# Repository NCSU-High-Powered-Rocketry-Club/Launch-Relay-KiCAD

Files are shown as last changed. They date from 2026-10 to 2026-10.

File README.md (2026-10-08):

# Launch Relay KiCad
This project contains the KiCad files for HPRC's Launch Relay board. This PCB was designed for the club's rover payload, which will be flown in the 2027 IREC competition.

## Description
The Launch Relay is designed to help conserve battery life and processing power of the rover payload by acting as a very low-power isolated solid-state relay. The board features an STM32 microcontroller, onboard flash for logging data, and an accelerometer to detect when the rocket launches and lands. It is all powered from a standard coin cell battery.

The firmware for the STM32 can be found [here](https://github.com/NCSU-High-Powered-Rocketry-Club/GildedTrigger).



## Component Overview
Here are the main components that the board uses:

| Component Type | Part Number | Datasheet |
|---|---|---|
| Microcontroller | STM32U083KCU6 | [STMicroelectronics](https://www.st.com/resource/en/datasheet/stm32u083kc.pdf) |
| Accelerometer | BMA580 | [Bosch Sensortec](https://www.bosch-sensortec.com/media/boschsensortec/downloads/datasheets/bst-bma580-ds000.pdf) |
| SPI NOR Flash (32 Mbit) | MX25R3235FM1IL0 | [Macronix](https://www.macronix.com/Lists/Datasheet/Attachments/8755/MX25R3235F%2C%20Wide%20Range%2C%2032Mb%2C%20v1.8.pdf) |
| D-Type Flip-Flop | SN74LVC1G74DQER | [Texas Instruments](https://www.ti.com/lit/ds/symlink/sn74lvc1g74.pdf) |
| N-Channel Power MOSFET | NVMFS5C460NLAFT1G-YE | [onsemi](https://www.onsemi.com/pdf/datasheet/nvmfs5c460nl-d.pdf) |

The STM32 was chosen for it's lower power consumption and small footprint, while still offering the needed peripherals for the board. The BMA580 accelerometer has excellent programmable interrupt features, allowing for customizable acceleration slopes and durations to be used to detect launch and wake the STM32. After launch, the acceleration data is stored to the MX25R3235F flash, which can be later retrieved for post-processing using the UART and DUMP pin provided on the pin header.

The board has two independent solid-state relays and are controlled using optocouplers. Optocouplers have relatively high power consumption compared to the rest of the board so a flip-flop circuit is used to limit the duration the optocoupler is powered. This powers the gate of the power MOSFET, which is wired as a low-side switch for the external circuit. Both relays on the board are designed for loads up to 10A. External circits must be at least 5.1V.

## Libraries
Some of the KiCad symbols and footprints for this project are not included in the standard KiCad library, and are located in [HPRC's KiCad Library](https://github.com/NCSU-High-Powered-Rocketry-Club/HPRC-KiCad-Library)

## PCBWay
A special thank you to our sponsor, [PCBWay](https://www.pcbway.com/), for supporting the manufacturing of this custom PCB! As a competitive high-powered rocketry team, reliable electronics are essential to the success of our projects. PCBWay's high-quality PCB manufacturing services have helped us turn our designs into functional hardware, allowing us to develop and test custom electronics for our rockets and payloads. Their support, attention to detail, and excellent communication throughout the manufacturing process have been greatly appreciated. We are grateful for their contribution to our team's success and highly recommend checking out their services for your next electronics project!



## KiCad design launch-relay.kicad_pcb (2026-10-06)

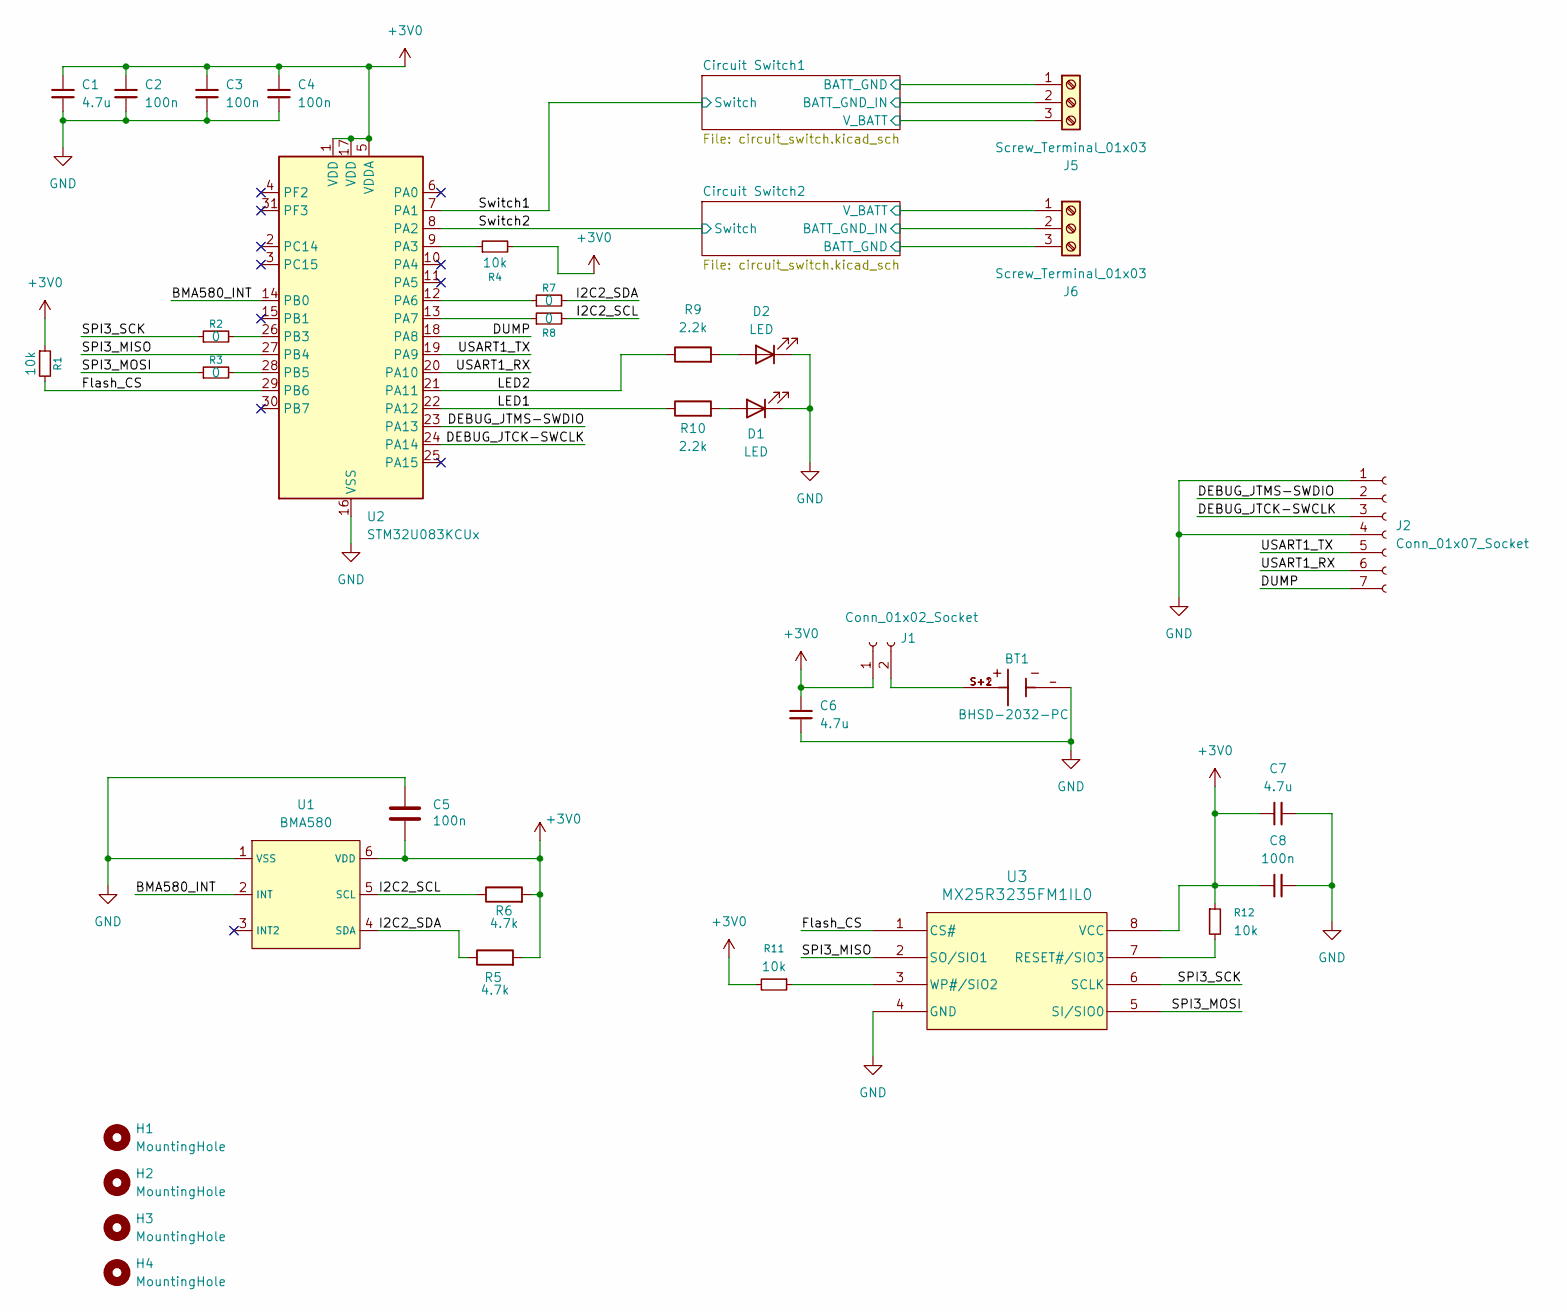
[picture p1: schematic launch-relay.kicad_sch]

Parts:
BT1: BHSD-2032-PC; BAT_BHSD-2032-PC; PARTREV K
C1, C6, C7: 4.7u; C_0402_1005Metric; Manufacturer_Part_Number GRM155R60J475ME47D
C2, C3, C4, C5, C8: 100n; C_0402_1005Metric; Manufacturer_Part_Number GRM155R61A104KA01D
D1: LED; LED_0805_2012Metric; Manufacturer_Part_Number APT2012SURCK
D2: LED; LED_0805_2012Metric; Manufacturer_Part_Number APT2012CGCK
H1, H2, H3, H4: MountingHole; MountingHole_2.2mm_M2
J1: Conn_01x02_Socket; PinSocket_1x02_P2.54mm_Vertical
J2: Conn_01x07_Socket; PinSocket_1x07_P2.54mm_Vertical
J5, J6: Screw_Terminal_01x03; TerminalBlock_Philmore_TB133_1x03_P5.00mm_Horizontal
R1, R4, R11, R12: 10k; R_0402_1005Metric; Manufacturer_Part_Number RC0402FR-0710KL
R2, R3, R7, R8: 0; R_0402_1005Metric; Manufacturer_Part_Number RC0402FR-070RL
R5, R6: 4.7k; R_0402_1005Metric; Manufacturer_Part_Number RC0402FR-074k7L
R9, R10: 2.2k; R_0402_1005Metric; Manufacturer_Part_Number RC0402FR-072k2L
U1: BMA580; Manufacturer_Part_Number BMA580
U2: STM32U083KCUx; QFN-32-1EP_5x5mm_P0.5mm_EP3.45x3.45mm; Manufacturer_Part_Number STM32U083KCU6
U3: MX25R3235FM1IL0; SOP_8L_150_MAC; Manufacturer_Part_Number MX25R3235FM1IL0

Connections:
+3V0: C1.2, C2.2, C3.2, C4.2, C5.2, C6.2, C7.1, C8.1, J1.1, R1.1, R4.2, R5.2, R6.2, R11.2, R12.1, U1.6 (VDD), U2.1 (VDD), U2.5 (VDDA), U2.17 (VDD), U3.8 (VCC)
/BMA580_INT: U1.2 (INT), U2.14 (PB0)
/Circuit Switch1/BATT_GND: J5.1; also elsewhere on the board
/Circuit Switch1/BATT_GND_IN: J5.2; also elsewhere on the board
/Circuit Switch1/V_BATT: J5.3; also elsewhere on the board
/Circuit Switch2/BATT_GND: J6.3; also elsewhere on the board
/Circuit Switch2/BATT_GND_IN: J6.2; also elsewhere on the board
/Circuit Switch2/V_BATT: J6.1; also elsewhere on the board
/DEBUG_JTCK-SWCLK: J2.3, U2.24 (PA14)
/DEBUG_JTMS-SWDIO: J2.2, U2.23 (PA13)
/DUMP: J2.7, U2.18 (PA8)
/Flash_CS: R1.2, U2.29 (PB6), U3.1 (CS#)
/I2C2_SCL: R6.1, R8.2, U1.5 (SCL)
/I2C2_SDA: R5.1, R7.2, U1.4 (SDA)
/LED1: R10.1, U2.22 (PA12)
/LED2: R9.1, U2.21 (PA11)
/SPI3_MISO: U2.27 (PB4), U3.2 (SO/SIO1)
/SPI3_MOSI: R3.1, U3.5 (SI/SIO0)
/SPI3_SCK: R2.1, U3.6 (SCLK)
/Switch1: U2.7 (PA1); also elsewhere on the board
/Switch2: U2.8 (PA2); also elsewhere on the board
/USART1_RX: J2.6, U2.20 (PA10)
/USART1_TX: J2.5, U2.19 (PA9)
GND: BT1.-, C1.1, C2.1, C3.1, C4.1, C5.1, C6.1, C7.2, C8.2, D1.1 (K), D2.1 (K), J2.1, J2.4, U1.1 (VSS), U2.16 (VSS), U2.32 (VSS), U2.33 (VSS), U3.4 (GND); also elsewhere on the board
unnamed: D1.2 (A), R10.2
unnamed: D2.2 (A), R9.2
unnamed: BT1.S+1, BT1.S+2, J1.2
unnamed: R4.1, U2.9 (PA3)
unnamed: R7.1, U2.12 (PA6)
unnamed: R8.1, U2.13 (PA7)
unnamed: R2.2, U2.26 (PB3)
unnamed: R3.2, U2.28 (PB5)
unnamed: R12.2, U3.7 (RESET#/SIO3)
unnamed: R11.1, U3.3 (WP#/SIO2)

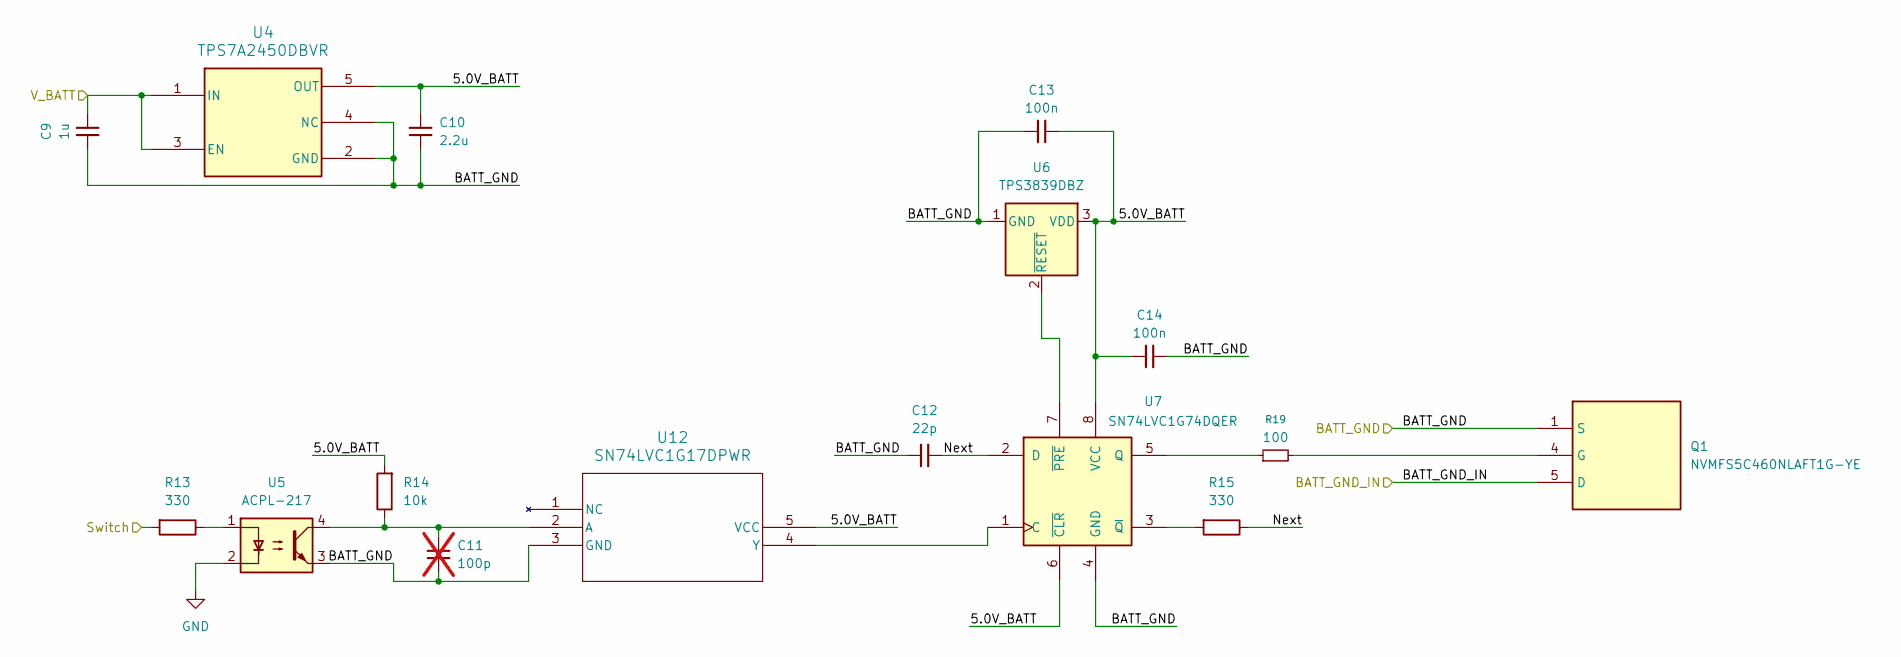
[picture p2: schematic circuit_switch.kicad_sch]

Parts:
C9: 1u; C_0402_1005Metric; Manufacturer_Part_Number GRM155R61E105MA12D
C10: 2.2u; C_0402_1005Metric; Manufacturer_Part_Number GRT155R61A225KE01D
C11: 100p; C_0402_1005Metric; not fitted
C12: 22p; C_0402_1005Metric; Manufacturer_Part_Number GRM1555C1H220JA01D
C13, C14: 100n; C_0402_1005Metric; Manufacturer_Part_Number GRM155R61A104KA01D
Q1: NVMFS5C460NLAFT1G-YE; NVMFS3D0P04M8LT1G; Manufacturer_Part_Number NVMFS5C460NLAFT1G-YE
R13, R15: 330; R_0402_1005Metric; Manufacturer_Part_Number RC0402FR-07330RL
R14: 10k; R_0402_1005Metric; Manufacturer_Part_Number RC0402FR-0710KL
R19: 100; R_0402_1005Metric; Manufacturer_Part_Number RC0402FR-07100RL
U4: TPS7A2450DBVR; SOT-23-5; Manufacturer_Part_Number TPS7A2450DBVR
U5: ACPL-217; SO-4_4.4x2.3mm_P1.27mm; Manufacturer_Part_Number ACPL-217-56CE
U6: TPS3839DBZ; SOT-23; Manufacturer_Part_Number TPS3839K50DBZR
U7: SN74LVC1G74DQER; X2SON-8_1.4x1mm_P0.35mm; Manufacturer_Part_Number SN74LVC1G74DQER
U12: SN74LVC1G17DPWR; Manufacturer_Part_Number SN74LVC1G17DPWR

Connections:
/Circuit Switch1/5.0V_BATT: C10.1, C13.1, C14.2, R14.2, U4.5 (OUT), U6.3 (VDD), U7.6 (~CLR), U7.8 (VCC), U12.5 (VCC)
/Circuit Switch1/BATT_GND: C9.1, C10.2, C11.1, C12.1, C13.2, C14.1, Q1.1 (S), Q1.2 (S), Q1.3 (S), U4.2 (GND), U4.4 (NC), U5.3, U6.1 (GND), U7.4 (GND), U12.3 (GND); also elsewhere on the board
/Circuit Switch1/BATT_GND_IN: Q1.5 (D), Q1.6 (D), Q1.7 (D), Q1.8 (D), Q1.9 (D); also elsewhere on the board
/Circuit Switch1/Next: C12.2, R15.1, U7.2 (D)
/Circuit Switch1/V_BATT: C9.2, U4.1 (IN), U4.3 (EN); also elsewhere on the board
/Switch1: R13.2; also elsewhere on the board
GND: U5.2; also elsewhere on the board
unnamed: Q1.4 (G), R19.2
unnamed: R13.1, U5.1
unnamed: U6.2 (~RESET), U7.7 (~PRE)
unnamed: R19.1, U7.5 (Q)
unnamed: R15.2, U7.3 (~Q)
unnamed: C11.2, R14.1, U5.4, U12.2 (A)
unnamed: U7.1 (C), U12.4 (Y)

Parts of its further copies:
C15: 1u; C_0402_1005Metric; Manufacturer_Part_Number GRM155R61E105MA12D
C16: 2.2u; C_0402_1005Metric; Manufacturer_Part_Number GRT155R61A225KE01D
C17: 100p; C_0402_1005Metric; not fitted
C18: 22p; C_0402_1005Metric; Manufacturer_Part_Number GRM1555C1H220JA01D
C19, C20: 100n; C_0402_1005Metric; Manufacturer_Part_Number GRM155R61A104KA01D
Q2: NVMFS5C460NLAFT1G-YE; NVMFS3D0P04M8LT1G; Manufacturer_Part_Number NVMFS5C460NLAFT1G-YE
R16, R18: 330; R_0402_1005Metric; Manufacturer_Part_Number RC0402FR-07330RL
R17: 10k; R_0402_1005Metric; Manufacturer_Part_Number RC0402FR-0710KL
R20: 100; R_0402_1005Metric; Manufacturer_Part_Number RC0402FR-07100RL
U8: TPS7A2450DBVR; SOT-23-5; Manufacturer_Part_Number TPS7A2450DBVR
U9: ACPL-217; SO-4_4.4x2.3mm_P1.27mm; Manufacturer_Part_Number ACPL-217-56CE
U10: TPS3839DBZ; SOT-23; Manufacturer_Part_Number TPS3839K50DBZR
U11: SN74LVC1G74DQER; X2SON-8_1.4x1mm_P0.35mm; Manufacturer_Part_Number SN74LVC1G74DQER
U13: SN74LVC1G17DPWR; Manufacturer_Part_Number SN74LVC1G17DPWR

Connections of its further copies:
/Circuit Switch2/5.0V_BATT: C16.1, C19.1, C20.2, R17.2, U8.5 (OUT), U10.3 (VDD), U11.6 (~CLR), U11.8 (VCC), U13.5 (VCC)
/Circuit Switch2/BATT_GND: C15.1, C16.2, C17.1, C18.1, C19.2, C20.1, Q2.1 (S), Q2.2 (S), Q2.3 (S), U8.2 (GND), U8.4 (NC), U9.3, U10.1 (GND), U11.4 (GND), U13.3 (GND); also elsewhere on the board
/Circuit Switch2/BATT_GND_IN: Q2.5 (D), Q2.6 (D), Q2.7 (D), Q2.8 (D), Q2.9 (D); also elsewhere on the board
/Circuit Switch2/Next: C18.2, R18.1, U11.2 (D)
/Circuit Switch2/V_BATT: C15.2, U8.1 (IN), U8.3 (EN); also elsewhere on the board
/Switch2: R16.2; also elsewhere on the board
GND: U9.2; also elsewhere on the board
unnamed: Q2.4 (G), R20.2
unnamed: R16.1, U9.1
unnamed: U10.2 (~RESET), U11.7 (~PRE)
unnamed: U11.1 (C), U13.4 (Y)
unnamed: R20.1, U11.5 (Q)
unnamed: R18.2, U11.3 (~Q)
unnamed: C17.2, R17.1, U9.4, U13.2 (A)

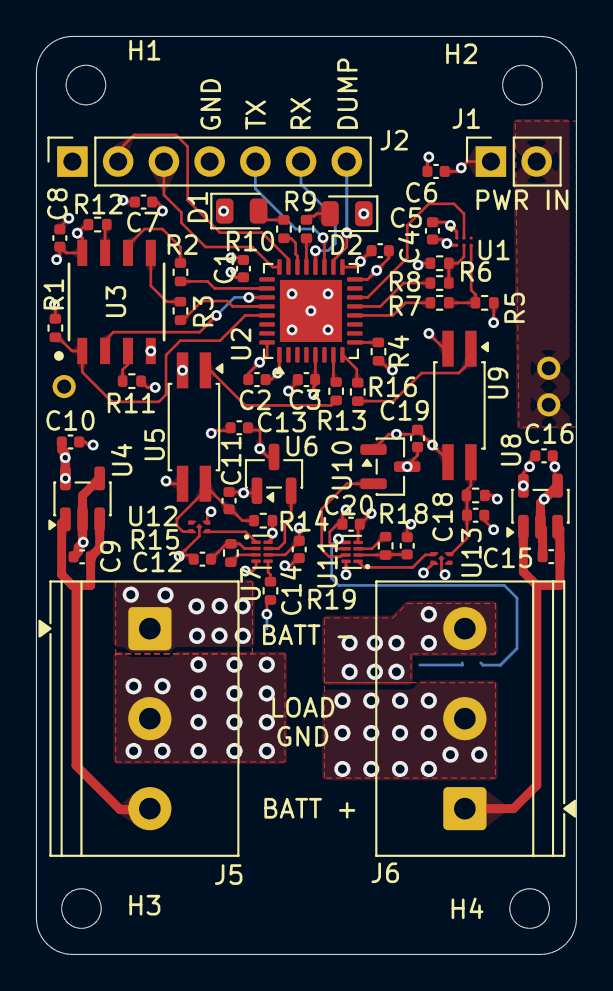
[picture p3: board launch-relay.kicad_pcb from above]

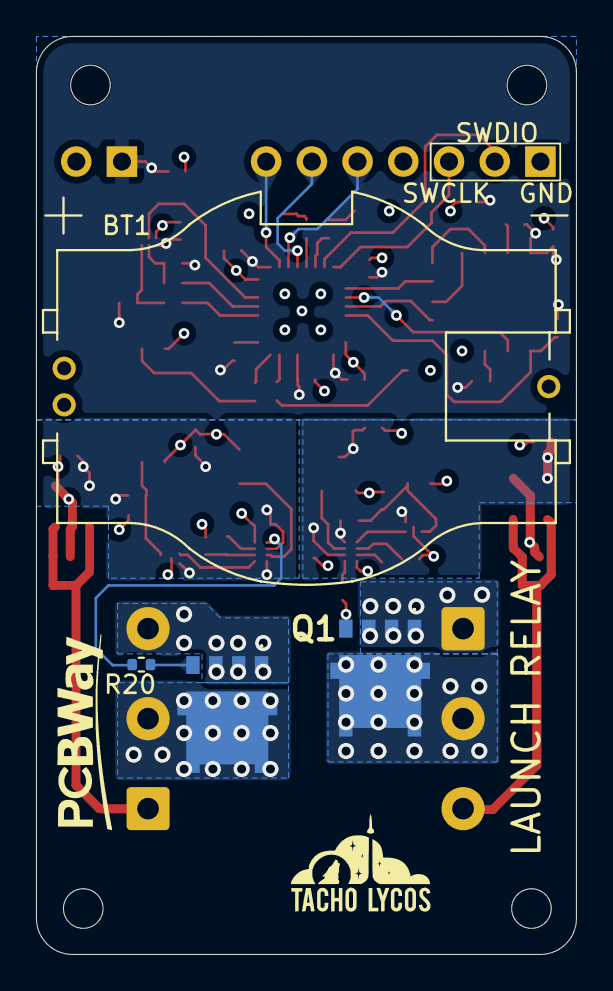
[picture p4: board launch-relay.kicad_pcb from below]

Board: 4 copper layers, 30.0 x 51.0 mm, 66 parts (4 on the bottom side), 52 nets.

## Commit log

2026-09-02 kicad project creation
    [launch-relay.kicad_pcb, launch-relay.kicad_sch]
2026-09-03 fix kicad version
    [launch-relay.kicad_pcb, launch-relay.kicad_sch]
2026-09-08 started schematic
    [launch-relay.kicad_sch]
2026-09-09 finalized schematic and prepped layout
    [circuit_switch.kicad_sch, launch-relay.kicad_pcb, launch-relay.kicad_sch]
2026-09-09 setup 6 layer board
    [launch-relay.kicad_pcb]
2026-09-11 fixed switch circuit
    [circuit_switch.kicad_sch, launch-relay.kicad_sch]
2026-09-21 removed bulk caps
    [circuit_switch.kicad_sch]
2026-10-02 ready to review
    [circuit_switch.kicad_sch, launch-relay.kicad_pcb, launch-relay.kicad_sch]
2026-10-06 ordered fr fr
    [launch-relay-B_Cu.gbr, launch-relay-B_Mask.gbr, launch-relay-B_Paste.gbr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]
2026-10-08 Enhance README with detailed PCBWay sponsorship info
    Expanded appreciation for PCBWay's support and services.
2026-10-08 changed PCBWay desc.
    Updated the description of PCBWay's services and experience.
